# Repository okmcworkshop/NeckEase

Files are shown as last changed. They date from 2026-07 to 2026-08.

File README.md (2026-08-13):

# NeckEase 頸智鬆 - 實體裝置 neGuard



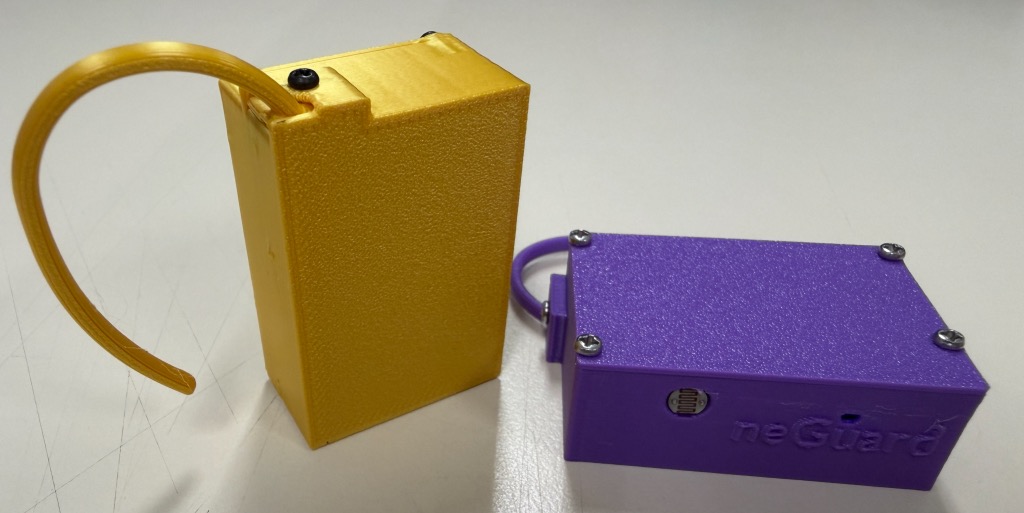
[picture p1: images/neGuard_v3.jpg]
neGuard圖片


📖 簡介
neGuard 是一個基於 ESP32-C3 的智慧姿勢矯正裝置。它能透過 BLE 與「NeckEase 頸智鬆」手機應用程式配對設定，之後便能離線獨立運作，即時監測你的頭部角度。當偵測到不良姿勢（如「烏龜頸」）過久時，neGuard 會以震動提醒，幫助你養成良好的姿勢習慣。

本專案專為 DIY 愛好者 及 STEAM 教育 設計，所有零件、程式碼和 3D 列印檔案皆已開源。我們希望藉此啟發對科技有興趣的同學，能一步一腳印地參考實踐，進而發揮創意，發明更多有益他人的作品。

✨ 功能特色
姿勢即時監測：內建 MPU-6050 陀螺儀，精準偵測頭部前傾角度。

離線獨立運作：與手機配對設定後，即可獨立使用，無需持續連接手機。

震動即時提醒：當姿勢不良時間超過設定值，內建震動馬達會溫和提醒。

低功耗藍牙 (BLE)：使用 ESP32-C3 的 BLE 功能，與手機應用程式進行配對與設定。

DIY 友善設計：採用常見、易於取得的電子零件，搭配 3D 列印外殼，組裝簡單。

** 與應用程式配對及設定之後，neGuard 保留參數儲存到 EEPROM，neGuard 開機30秒後會停止藍牙功能節省電力。如改動「角度閾值」和「持續時間」，在neGuard開機30秒內打開手機應用程式重新設定。 **

🧩 硬體需求
以下是製作 neGuard 所需的完整零件清單：
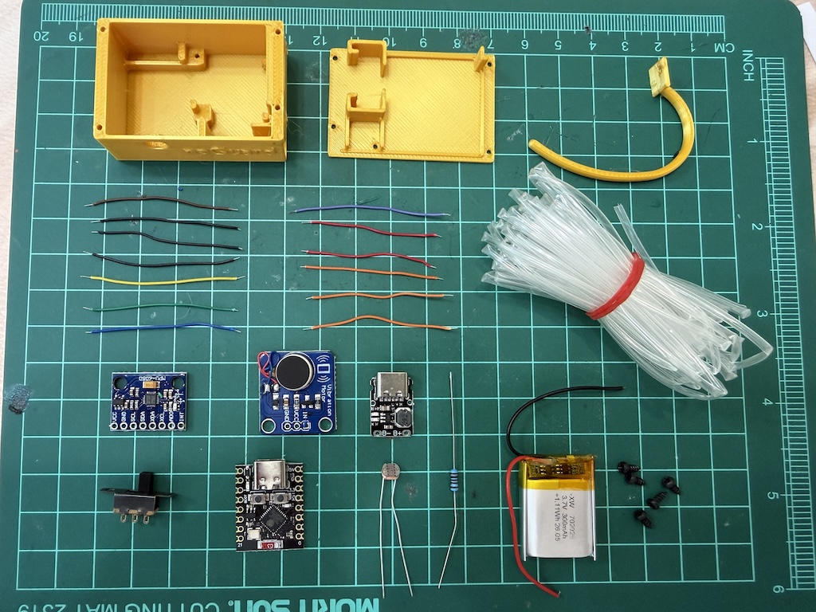
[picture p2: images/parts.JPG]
零件清單

### 硬體需求清單

- **微控制器**：ESP32-C3 Supermini 開發板 × 1（核心運算單元，支援 BLE）
- **陀螺儀**：MPU-6050 (I2C) × 1（偵測頭部角度）
- **光敏電阻**：5549 × 1（用於判斷環境光照度）
- **電阻**：10kΩ × 1（配合光敏電阻使用）
- **震動馬達模組**：1020 扁平震動馬達 × 1（提供震動提醒）
- **鋰電池充電模組**：5V 充電模組 (Type-C) × 1（為鋰電池充電）
- **電源開關**：SS-12F15 3腳2檔 滑動開關 × 1（控制裝置電源）
- **鋰電池**：702025 3.7V 300mAh LiPo × 1（裝置電源）
- **連接線**：AWG26 杜邦線/軟矽膠線（用於電路連接）
- **熱縮通**：少量(絕緣，避免短路)
- **螺絲**：M2x5不鏽鋼自攻螺絲 x 6
- **雙面膠**：少量(用於固定MPU6050 及 ESP32-C3)

🔧 組裝與設定指南
1. 電路連接 (接線圖)
請參考以下接線圖進行焊接。確保所有連接牢固，震動馬達及光敏電阻需加上熱縮通絕緣，避免短路。

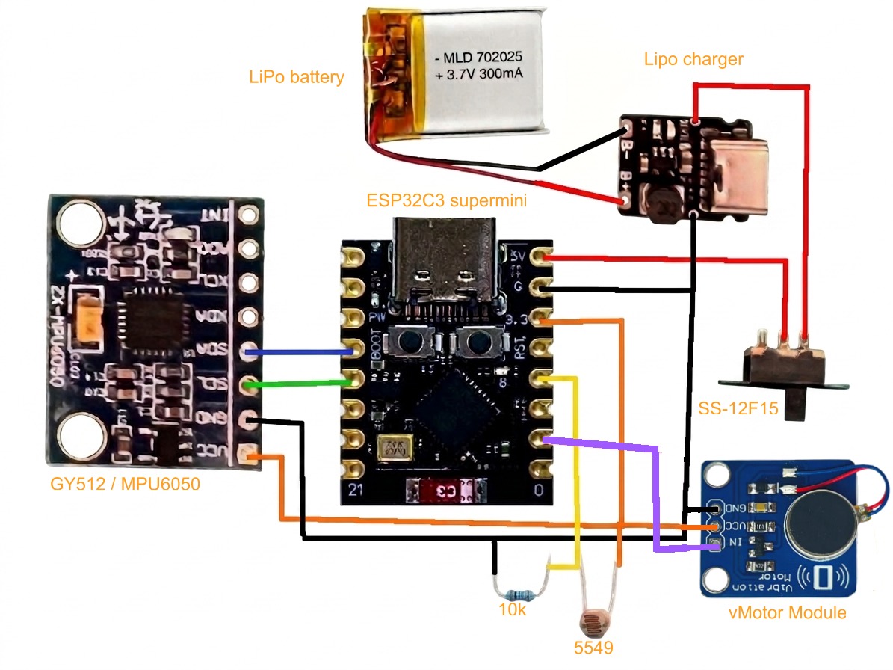
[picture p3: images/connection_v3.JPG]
接線圖


| 步驟 | 連接點 A | 連接點 B | 說明 |
| :---: | :--- | :--- | :--- |
| 1 | 外部 5V 電源 | ESP32-C3 5V 輸入端 | 為開發板提供電源 |
| 2 | ESP32-C3 3.3V | MPU-6050 VCC、光敏電阻一端、震動馬達正極 | 提供電源給 MPU-6050、光敏電阻分壓電路及震動馬達 |
| 3 | ESP32-C3 GND | 所有零件 GND（馬達、感測器、電晶體等） | 全部共地，形成完整迴路 |
| 4 | ESP32-C3 GPIO 1 | 震動馬達模組 IN | 輸出震動馬達控制訊號 |
| 5 | 光敏電阻 另一端 | GPIO 3 及 10kΩ 電阻 一端 | 分壓電路中間節點（ADC 讀取點） |
| 6 | 10kΩ 電阻 另一端 | ESP32-C3 GND | 分壓電路下端接地 |
| 7 | MPU-6050 SDA 腳位 | ESP32-C3 GPIO 8 | I2C 資料線 |
| 8 | MPU-6050 SCL 腳位 | ESP32-C3 GPIO 9 | I2C 時脈線 |
| 9 | MPU-6050 GND 腳位 | ESP32-C3 GND | 感測器接地 |

電路小提示：

# ESP32-C3 震動馬達模組 + 光敏電阻 驅動電路 (GPIO 1 控制馬達)

## 震動馬達模組驅動接線（GPIO 1）

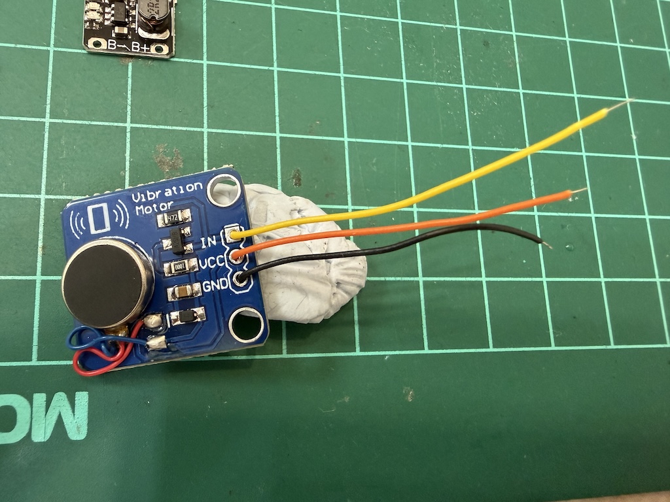
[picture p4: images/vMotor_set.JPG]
震動馬達 驅動電路


## 電路運作原理

- **GPIO 1 輸出高電平（3.3V）** → 模組內三極管基極獲得足夠電流 → 電晶體飽和導通 → 馬達獲得電流而振動。
- **GPIO 1 輸出低電平（0V）** → 電晶體截止 → 馬達停止。
- **續流二極體**：在馬達關斷瞬間，線圈產生反向感應電動勢（可達數十伏），二極體提供通路將其釋放，保護 三極管 不被擊穿。
- **光敏電阻**：光線越暗，阻值越大，分壓點電壓越高（ADC 數值越大）；光線越亮，阻值越小，電壓越低。

- NPN 電晶體開關原理是：電流從 C 流向 E（C → E），所以 負載（馬達）要接在 C 腳，E 腳要直接接地，這樣開關才能完全導通。

- 二極體 是反向並聯在馬達兩端（陰極接正極、陽極接負極），用來吸收馬達關斷時產生的「反向感應電動勢」，保護 三極管 不被高壓擊穿。

## 光敏電阻（光線感測）接線（GPIO 3）

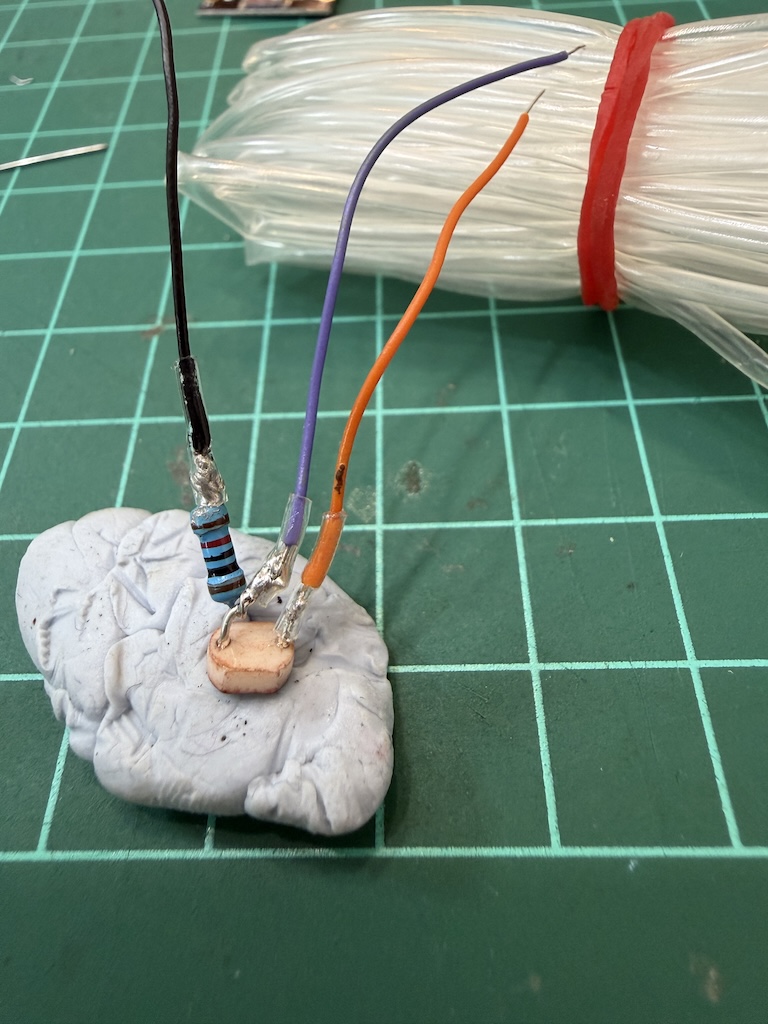
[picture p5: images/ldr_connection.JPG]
光敏電阻


| 步驟 | 連接點 A | 連接點 B | 說明 |
| :---: | :--- | :--- | :--- |
| 1 | 光敏電阻 **一端** | ESP32-C3 **3.3V** | 分壓電路上端 |
| 2 | 光敏電阻 **另一端** | **10kΩ 電阻** 之一端 及 **GPIO 3** | 分壓節點（ADC 讀取點） |
| 3 | **10kΩ 電阻** 之另一端 | ESP32-C3 **GND** | 分壓電路下端 |

** 在焊接處加上熱縮通絕緣 **

## 為什麼需要「分壓電路」？

- ESP32-C3 的 ADC（類比數位轉換器）**只能讀取電壓（0~3.3V）**，無法直接讀取電阻值。
- 光敏電阻是一個**可變電阻**，單獨接到 GPIO 時，因 GPIO 輸入阻抗極高，幾乎無電流流過，電壓恆為 3.3V，無法感測變化。
- 因此必須串聯一顆固定電阻（10kΩ），形成電流迴路，根據歐姆定律，分壓點電壓會隨光敏電阻阻值變化而改變，ADC 才能讀出有意義的數值。
- 選用 **10kΩ** 是常見工程值，因典型光敏電阻在室內光下約 10k~20kΩ，此組合能使輸出電壓變化範圍最大且線性度佳。

## MPU6050（陀螺儀）I2C接線（GPIO 8 SDA, GPIO 9 SCL）

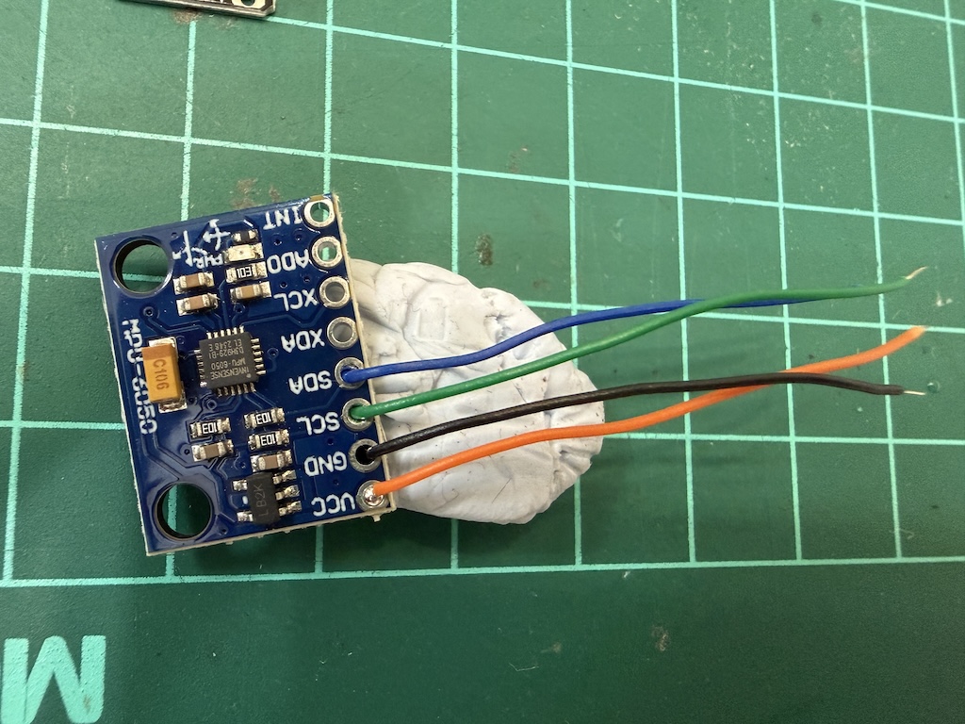
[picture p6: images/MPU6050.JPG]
MPU6050


## ESP32C3 以及 電源：

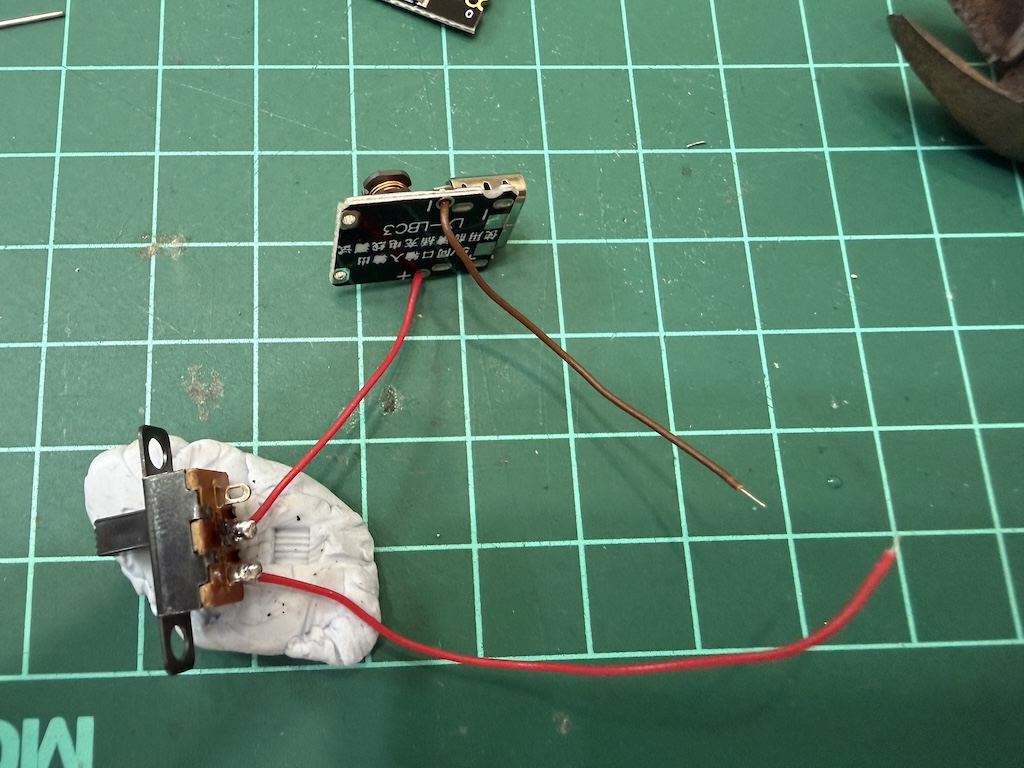
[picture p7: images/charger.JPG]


- 引出充電模組的 OUT- 和 OUT+ 經過「電源開關」。

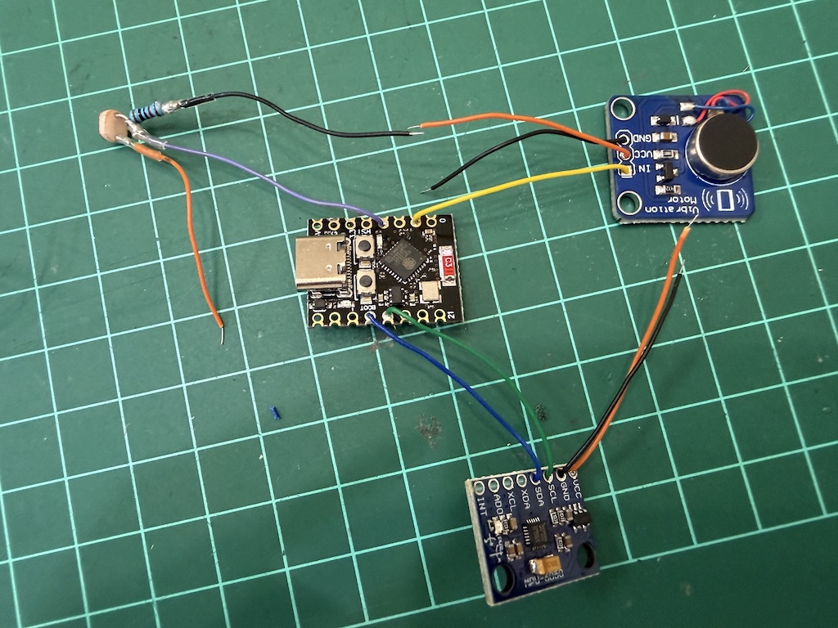
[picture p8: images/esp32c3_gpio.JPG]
ESP32C3


- MPU6050 SDA > 8，SCL > 9 。 震動馬達模組 IN > 1 。 光敏電阻 > 3 。

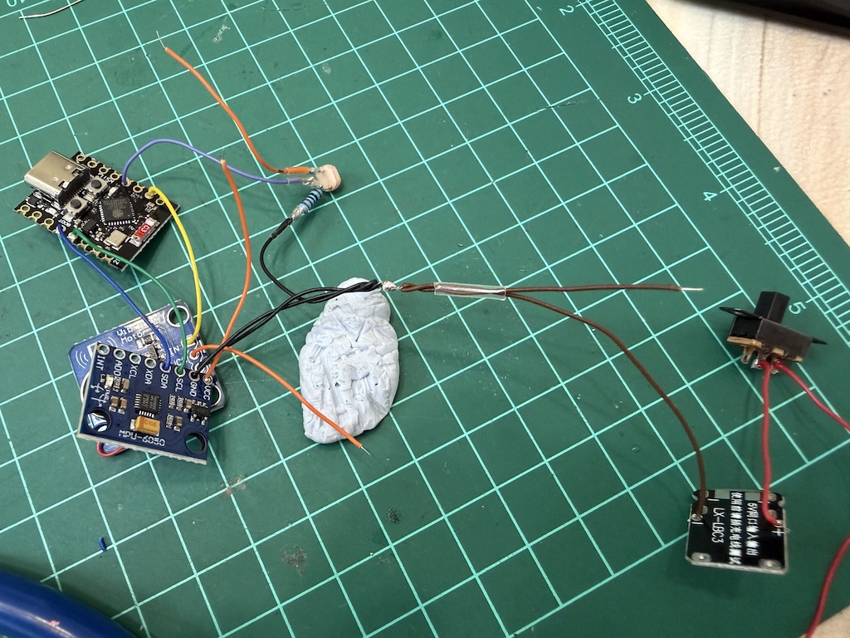
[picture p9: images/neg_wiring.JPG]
共地接線


- 充電模組的 OUT- 連接 MPU6050、震動馬達模組、光敏電阻 負極 並且引出 預留接駁ESP32C3 負極。

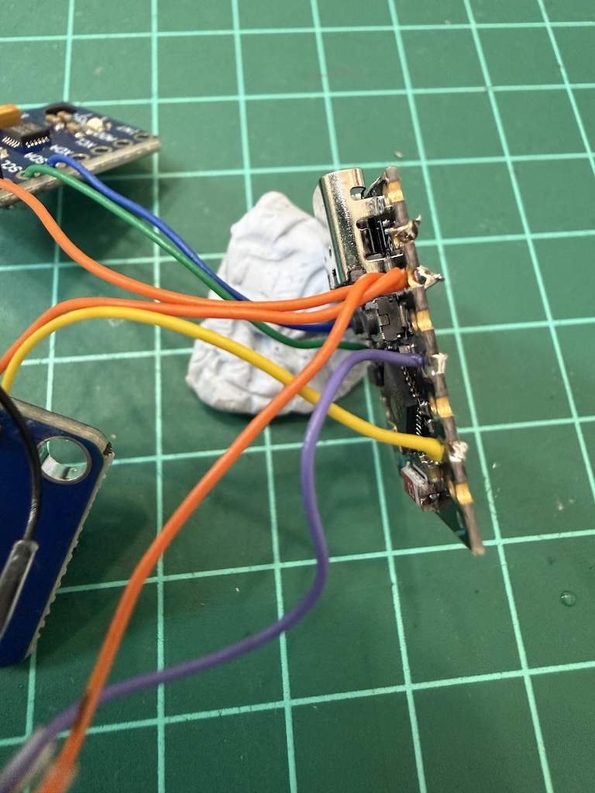
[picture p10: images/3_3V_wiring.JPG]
3.3V接線


- MPU6050、震動馬達模組、光敏電阻 正極連接 ESP32C3 3.3V

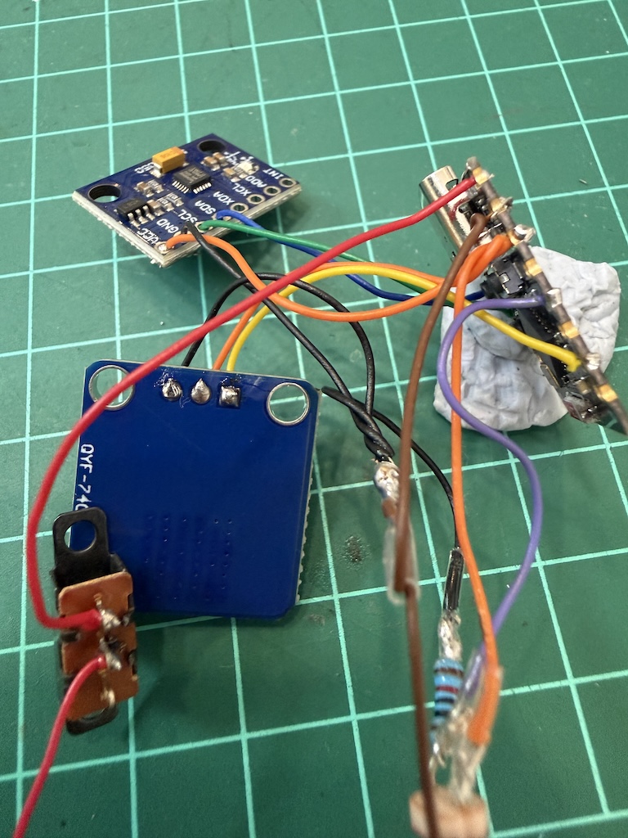
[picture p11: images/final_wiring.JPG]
5V接線


- OUT+經過「電源開關」接到 ESP32-C3 的 5V ，共地負極接駁ESP32C3 負極。

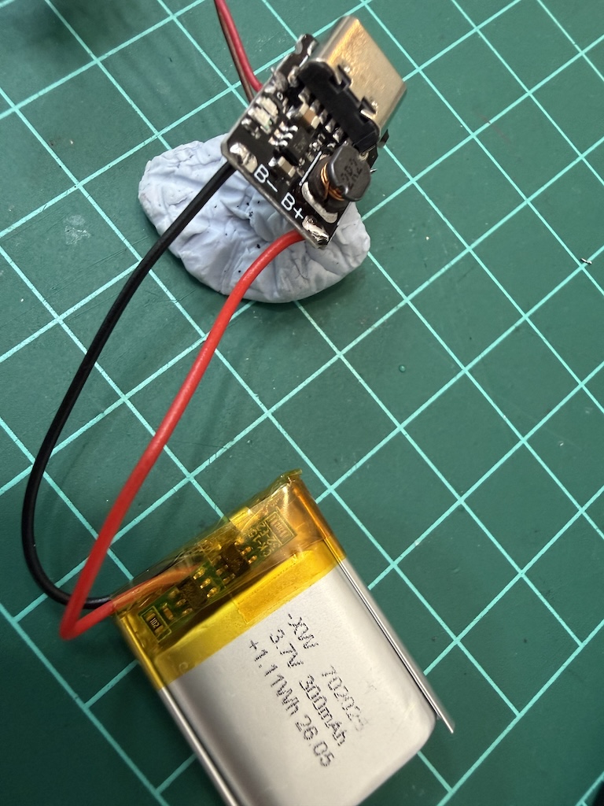
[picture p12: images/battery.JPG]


- 最後鋰電池透過「充電模組」的 BAT+ 和 BAT- 連接。

# 2. 3D 列印外殼

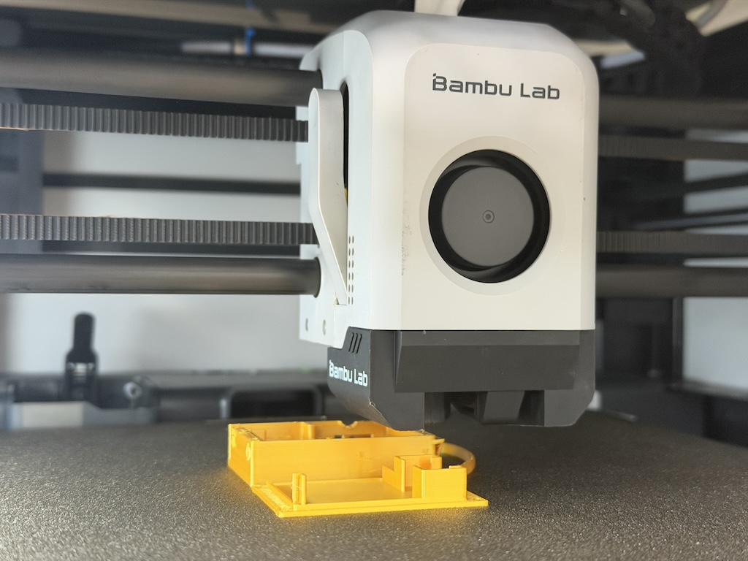
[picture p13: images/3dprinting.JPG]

請使用以下建議設定列印外殼。STL 檔案可以在 hardware/3d_print/ 資料夾中找到。

材料：PLA 或 PLA+ (約 10g)

噴嘴直徑：0.4mm

層高：0.28mm

外牆層數 (Wall Loops)：3

填充率：20%

支撐：不需要支撐。

備有大小掛耳，適配不同人士使用。

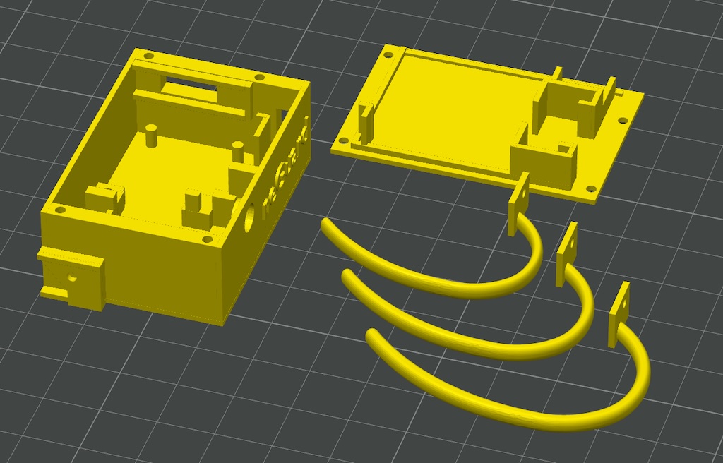
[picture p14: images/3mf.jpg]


# 3. 軟體燒錄 (韌體)
韌體使用 C++ 編寫，在 Arduino IDE 中開發。

安裝 Arduino IDE：從 官方網站 下載並安裝。

安裝 ESP32 開發板套件：

開啟 Arduino IDE，進入 檔案 > 偏好設定。

在「額外的開發板管理器網址」中，加入：https://espressif.github.io/arduino-esp32/package_esp32_index.json

進入 工具 > 開發板 > 開發板管理員，搜尋 esp32 並安裝 esp32 套件。

安裝所需的程式庫：

在 草稿碼 > 匯入程式庫 > 管理程式庫 中，搜尋並安裝：

MPU6050 by Electronic Cats (或 Adafruit MPU6050)

ESP32 BLE Arduino (通常已內建)

開啟韌體專案：

下載本倉庫的程式碼，在 Arduino IDE 中開啟 firmware/neGuard_v2.ino 檔案。

選擇開發板與連接埠：

在 工具 > 開發板 中，選擇 ESP32C3 Dev Module。

在 工具 > 連接埠 中，選擇你的 ESP32-C3 對應的 COM 連接埠。

上傳程式碼：

點擊 「上傳」 按鈕。等待編譯並上傳完成。

# 4. 組裝說明

第1步) 先檢查電線有否破損、斷裂或其他可能導致短路的情況

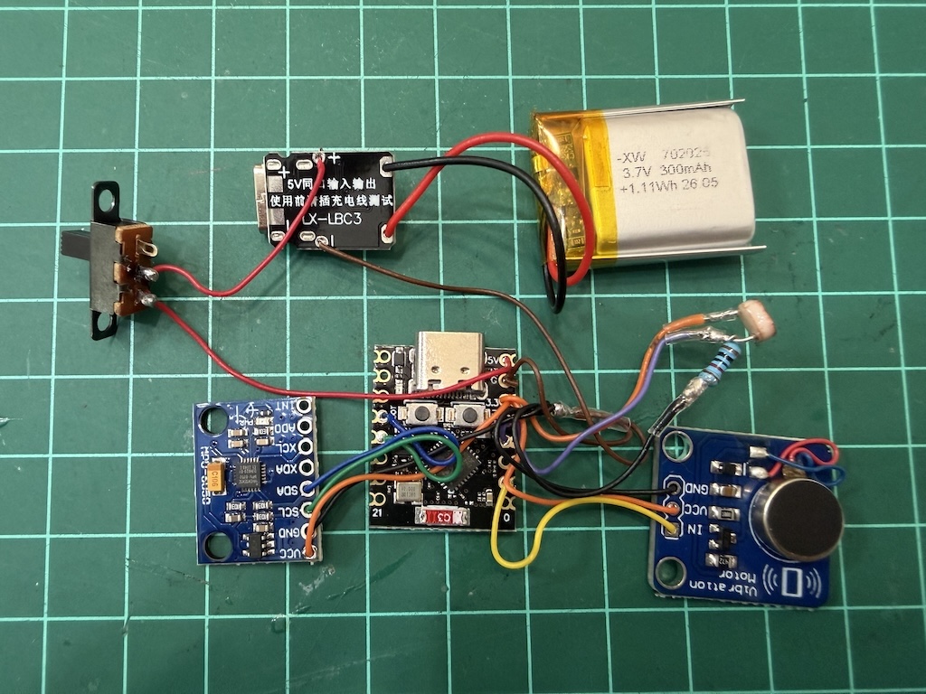
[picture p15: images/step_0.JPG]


將 neGuard 開關掣撥到接通，進行測試 > 開啟"NeckEase 頸智鬆" 應用程式 > "姿態提示" 頁面 > 點擊螢幕有上方藍牙 icon
如果顯示 "已找到 neGuard" > 關閉 neGuard 電源繼續組裝程序

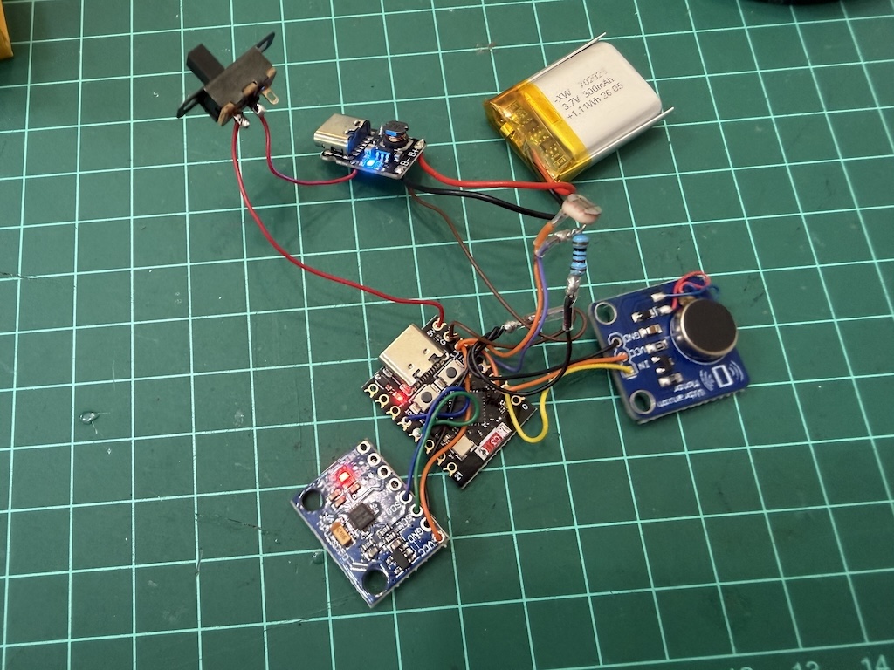
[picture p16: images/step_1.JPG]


第2步) 將充電模組放入3D打印外殼

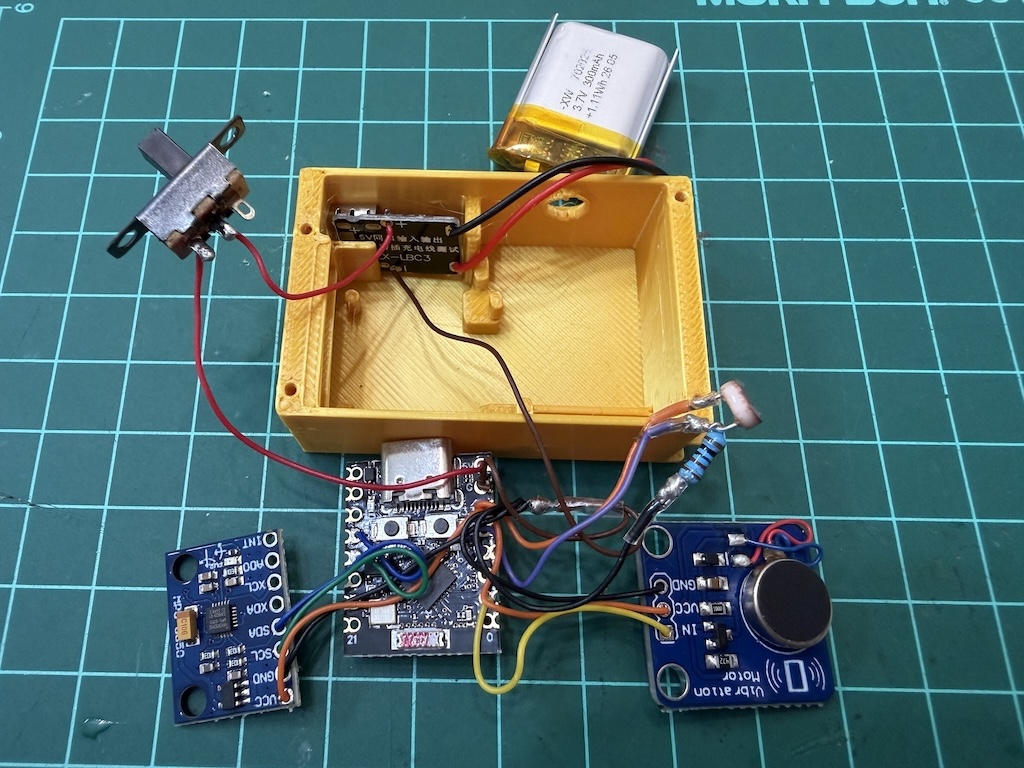
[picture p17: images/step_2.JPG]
組裝說明 - 2


第3步) MPU6050 及 ESP32C3 背面加上雙面膠

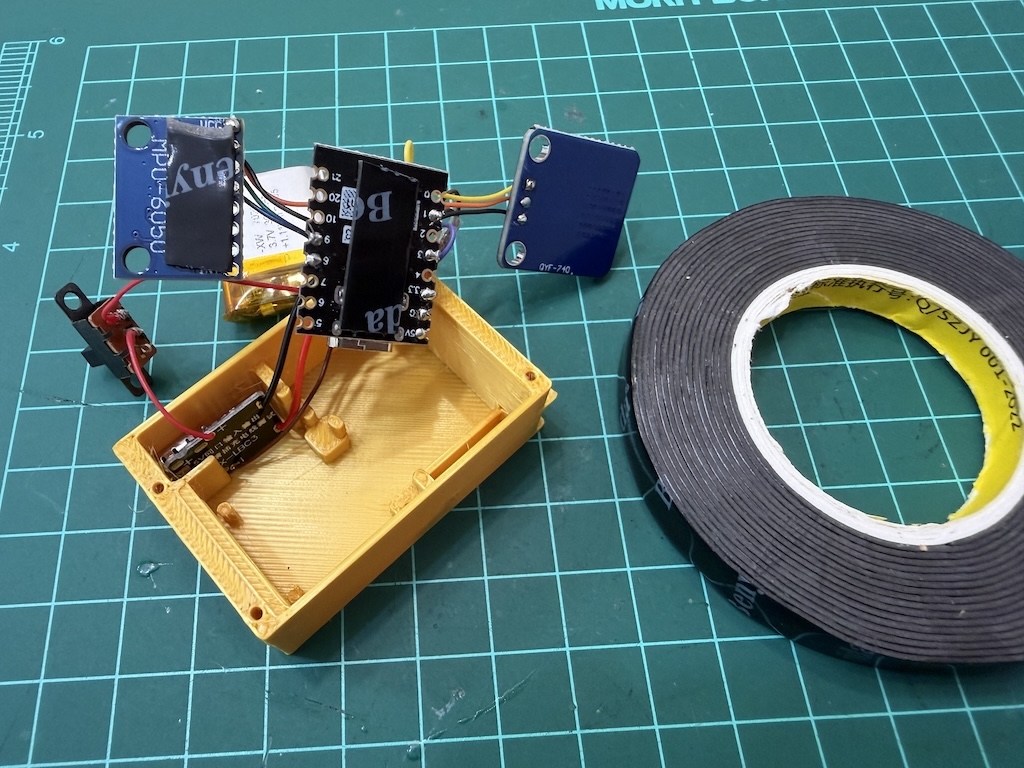
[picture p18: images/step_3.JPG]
組裝說明 - 3


第4步) 放入 MPU6050 及 ESP32-C3，稍加壓力固定 

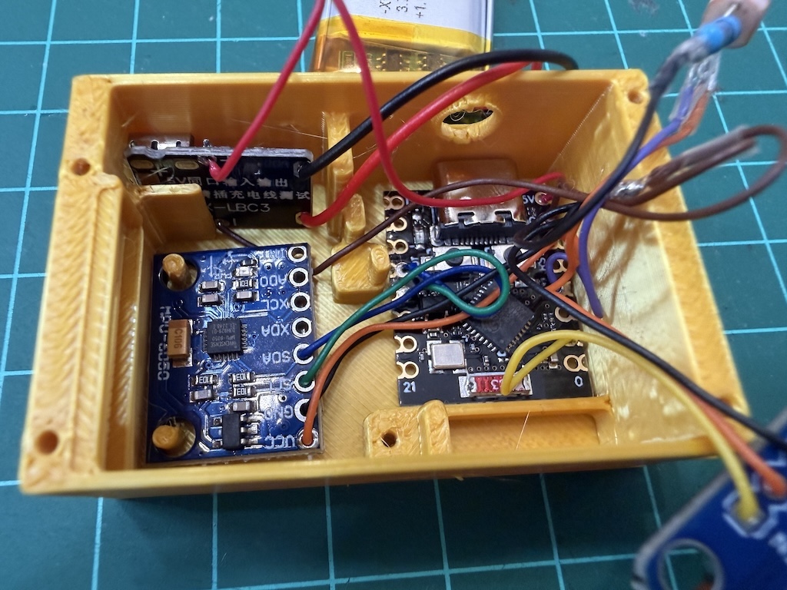
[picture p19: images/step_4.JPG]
組裝說明 - 4


第5步) 放入 5549 光敏電阻

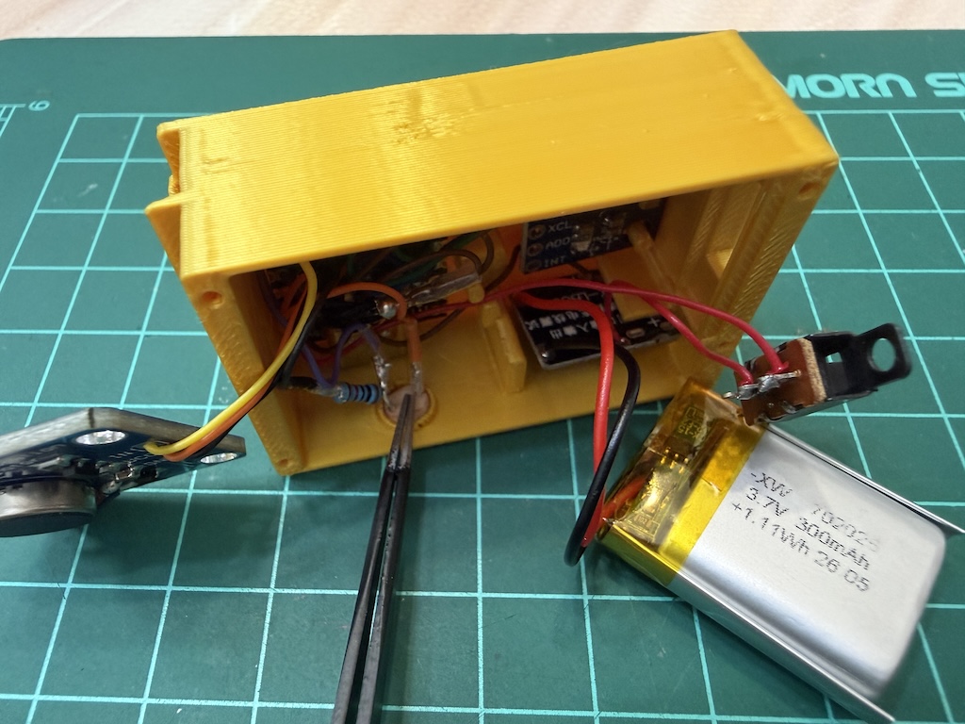
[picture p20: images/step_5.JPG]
組裝說明 - 5


第6步) 將震動馬達及模組主板分離(不處理有機會放不進外殼)

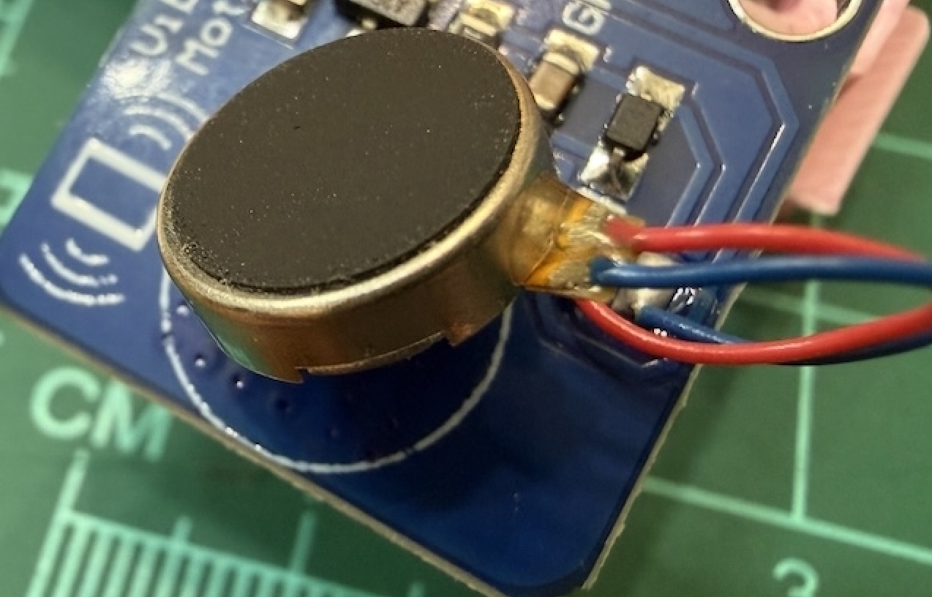
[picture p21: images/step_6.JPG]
組裝說明 - 6


第7步) 如圖片顯示把震動馬達放好並固定(留意電線位置)

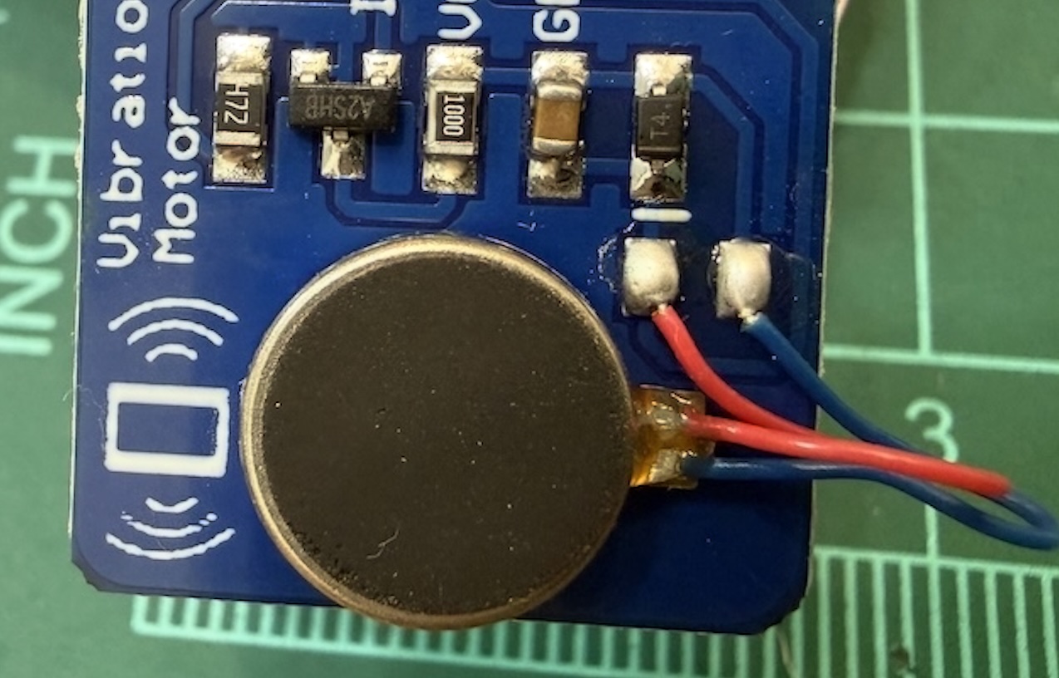
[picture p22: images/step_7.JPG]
組裝說明 - 7


第8步) 放入 震動馬達模組，並用螺絲固定好

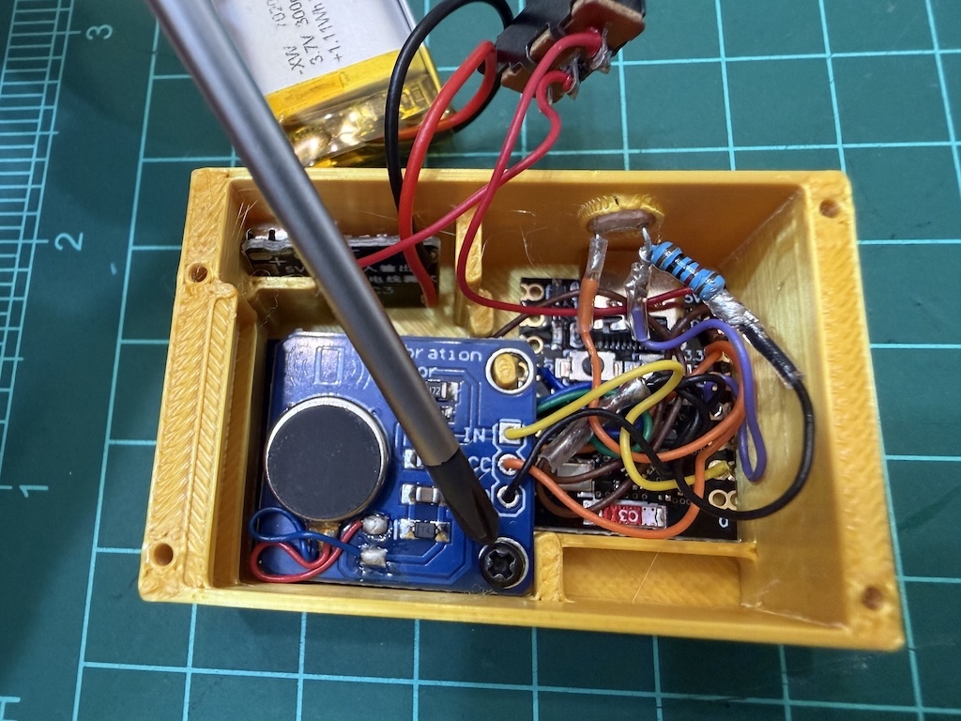
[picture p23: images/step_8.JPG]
組裝說明 - 8


第9步) 電池放在外殼頂蓋

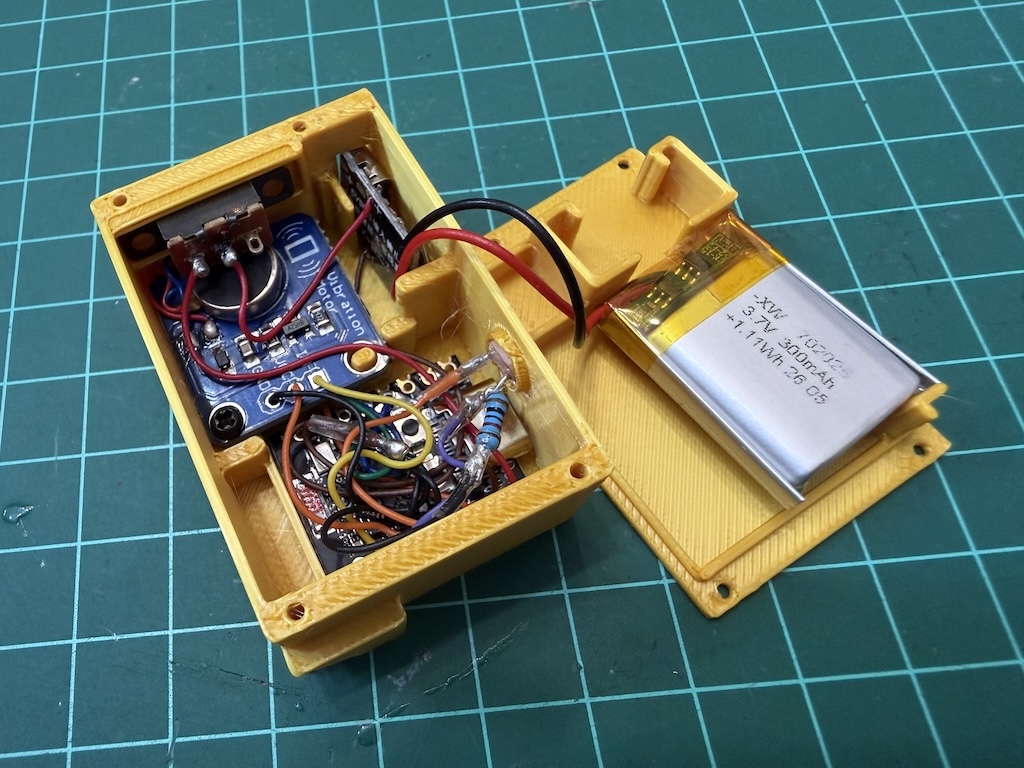
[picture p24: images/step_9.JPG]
組裝說明 - 9


第10步) 蓋好頂蓋，並用螺絲固定好

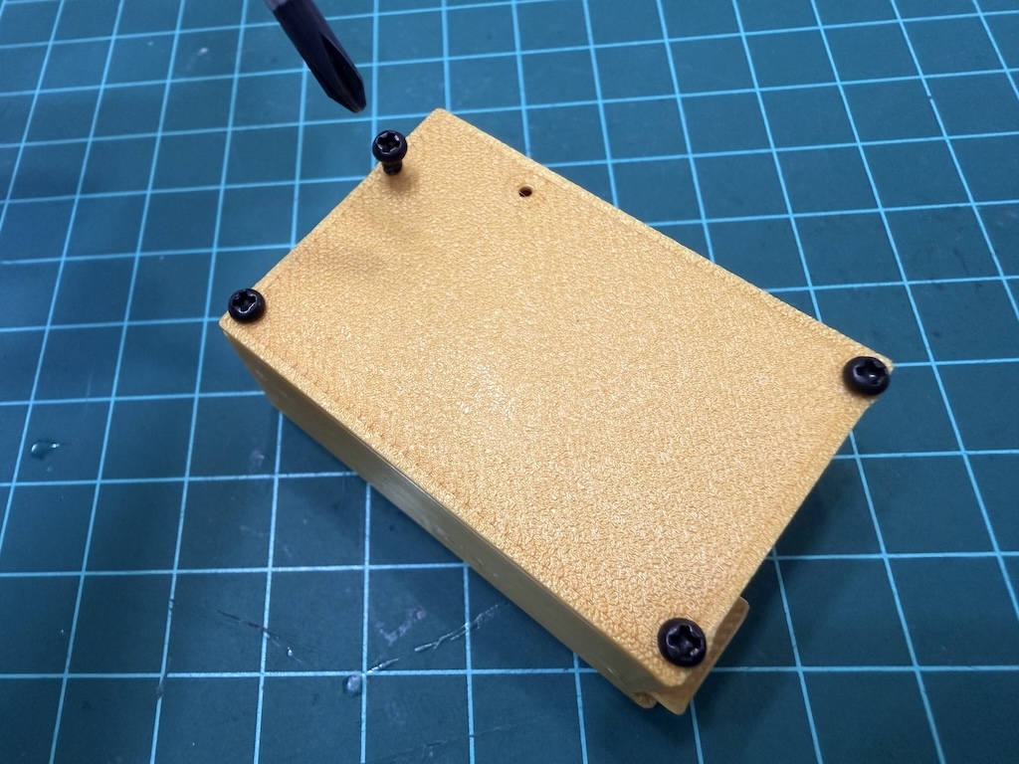
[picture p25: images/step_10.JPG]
組裝說明 - 10


第11步) 加上掛耳

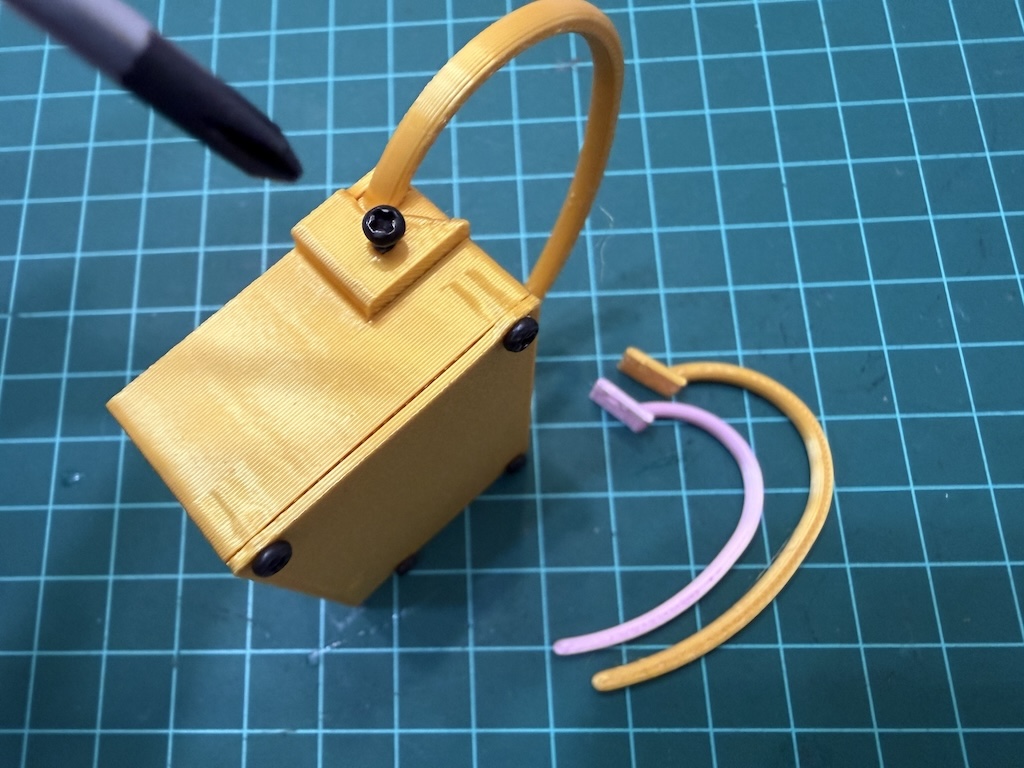
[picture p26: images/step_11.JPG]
組裝說明 - 11


# 恭喜你完成了

# 📱 使用說明
下載手機應用程式：在 Google Play 或 App Store 商店搜尋並下載 「NeckEase 頸智鬆」。

開啟裝置電源：將 neGuard 的電源開關撥至「ON」位置。

配對與設定：

打開手機應用程式，點擊「姿態提示」功能。

按下螢幕右上方"藍牙"標誌，會自動掃描附近的 neGuard 裝置，點擊進行配對。

依照手機畫面上的引導，設定提醒的「角度閾值」和「持續時間」。

開始使用：設定完成後，將 neGuard 夾在(左)耳朵上。當你的頭部前傾角度超過設定值且持續時間過長時，neGuard 便會震動提醒你。此後，即使手機不在身邊，neGuard 也能獨立工作。

** 與應用程式配對及設定之後，neGuard 保留參數儲存到 EEPROM，neGuard 開機30秒後會停止藍牙功能節省電力。如改動「角度閾值」和「持續時間」，在neGuard開機30秒內打開手機應用程式重新設定。 **

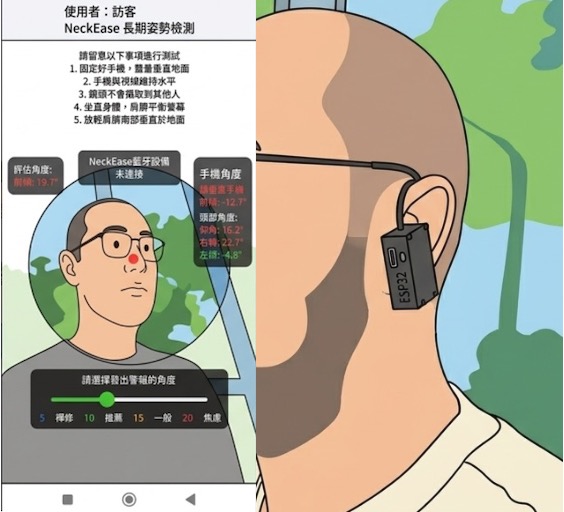
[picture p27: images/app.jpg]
產品圖片


# 📜 授權資訊
本專案 (包含韌體、硬體設計檔案、3D 列印檔案) 採用 MIT License 開源授權。

這意味著你可以：

✅ 自由使用、複製、修改、合併、出版發行、散布、再授權及販售軟體及硬體檔案的副本。

✅ 將本專案用於任何用途，包括商業用途。

唯一的條件是：你必須在所有的副本或重要部分中，包含版權聲明及本許可聲明。

詳細授權條款請參閱本倉庫的 LICENSE 檔案。

# 🤝 如何貢獻
我們非常歡迎任何形式的貢獻！如果你有好的想法、發現了 Bug，或是想改善文件，歡迎：

Fork 本專案。

建立你的功能分支 (git checkout -b feature/AmazingFeature)。

提交你的修改 (git commit -m 'Add some AmazingFeature')。

推送至分支 (git push origin feature/AmazingFeature)。

開啟一個 Pull Request。

祝你組裝愉快，輕鬆告別烏龜頸！

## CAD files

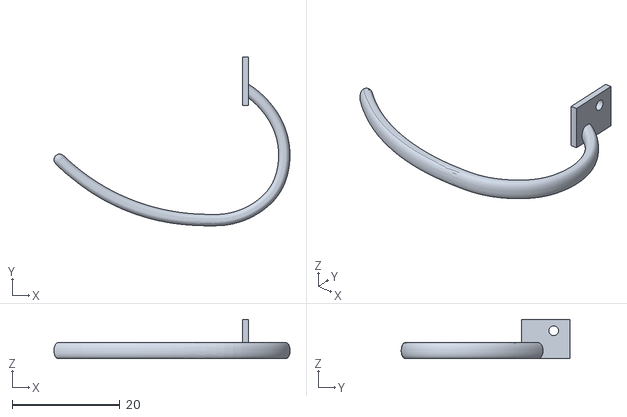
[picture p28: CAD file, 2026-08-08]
hardware/3d_print/V3_ear_clip_M.stl
43.8 x 31.3 x 7.32

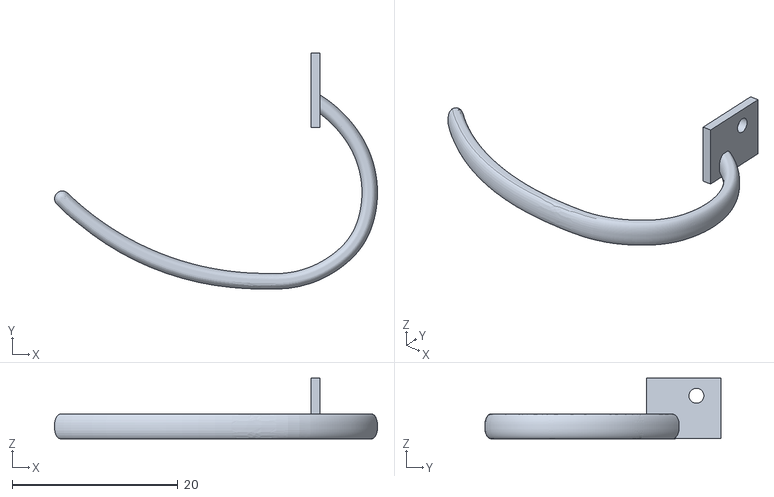
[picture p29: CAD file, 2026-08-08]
hardware/3d_print/V3_ear_clip_S.stl
39.0 x 28.5 x 7.32

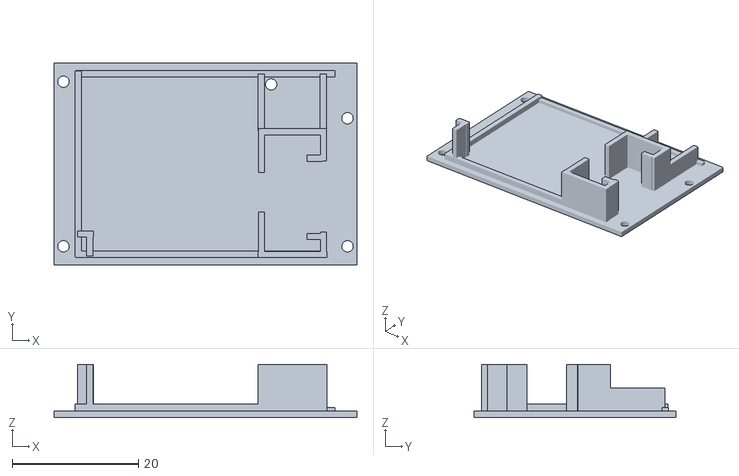
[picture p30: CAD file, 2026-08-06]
hardware/3d_print/neGuard_V3_cover.stl
48.0 x 32.0 x 8.40

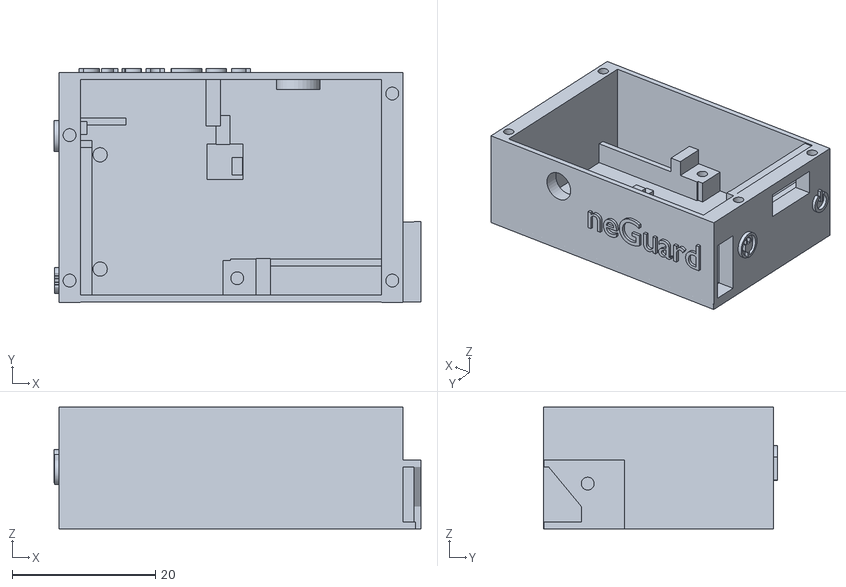
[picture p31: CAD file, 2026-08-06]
hardware/3d_print/neGuard_V3.stl
51.2 x 32.6 x 17.0

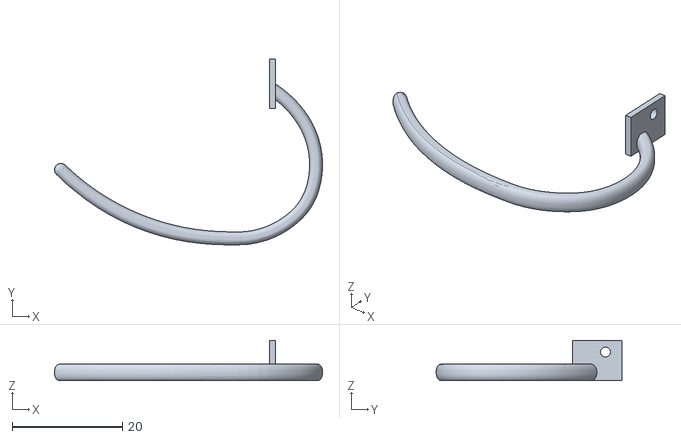
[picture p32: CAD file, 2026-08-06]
hardware/3d_print/V3_ear_clip_L.stl
48.7 x 33.7 x 7.32

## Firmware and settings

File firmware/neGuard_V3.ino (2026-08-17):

#include <Wire.h>
#include <BLEDevice.h>
#include <BLEUtils.h>
#include <BLEServer.h>
#include <Preferences.h>
#include <MPU6050_tockn.h>
#include <esp_sleep.h>  // 引入睡眠管理標頭檔
#include <WiFi.h>       // 用於確保 Wi-Fi 模組徹底關閉
#include "esp_bt.h"

MPU6050 mpu6050(Wire);

// ---------- 感測器資料結構 ----------
struct SensorData {
  float roll;
  float pitch;
  int ldr;
  float volt;
};

// ---------- BLE UUID ----------
#define SERVICE_UUID "6E400001-B5A3-F393-E0A9-E50E24DCCA9E"
#define IMU_CHAR_UUID "6E400002-B5A3-F393-E0A9-E50E24DCCA9F"
#define SWITCH_CHAR_UUID "6E400003-B5A3-F393-E0A9-E50E24DCCA9E"

// ---------- 全域 BLE 物件 ----------
BLEServer* pServer = NULL;
BLECharacteristic* pImuCharacteristic = NULL;
BLECharacteristic* pSwitchCharacteristic = NULL;

// ---------- 姿勢與濾波變數 ----------
float angleRoll = 0, anglePitch = 0;
float dt = 0;
unsigned long lastTime = 0;
unsigned long lastHighFreqUpdate = 0;
float alpha = 0.05;

// 腳位設定
const int LIGHT_SENSOR_PIN = 3;  // GPIO3
const int V_MOTOR_PIN = 1;       // GPIO1

// 警報與狀態標誌
unsigned long alarmStartTime = 0;
unsigned long lastBlinkTime = 0;
int _BlinkCap = 1000;
bool alarmActive = false;
bool deviceConnected = false;
int postureStartTime = 0;

// 校準與姿態判斷變數
float calRoll_10 = 0, calRoll_15 = 0, calRoll_20 = 0, calRoll_25 = 0;  // 對應前傾的 Gyro Roll
float thresholdRoll = 0;                                               // 使用者選擇的閾值所對應的 Gyro Roll
int durationSeconds = 5;                                               // 持續時間（秒）
bool calibrated = false;                                               // 是否已收到校準資料

//unsigned long postureStartTime = 0;  // 姿勢不良開始計時的時間點
bool alertTriggered = false;         // 是否已觸發振動提醒（持續振動中）

// BLE 計時與儲存
Preferences preferences;         // Preferences 物件
bool bleActive = false;          // 是否處於廣播有效期間（用於計時控制）
bool bleInitialized = false;     // 是否已初始化 BLE（避免重複 deinit）
unsigned long bleStartTime = 0;  // 開始計時的時間點

// ---------- 輔助函式：馬達震動  ----------
void blinkMotor(int times) {
  for (int i = 0; i < times; i++) {
    digitalWrite(V_MOTOR_PIN, HIGH);
    delay(200);
    digitalWrite(V_MOTOR_PIN, LOW);
    delay(100);
  }
}

// ---------- 用於連線debug  ----------
void _print_gyro_data() {
  Serial.print("Roll: ");
  Serial.print(angleRoll, 2);
  Serial.print("\tPitch: ");
  Serial.println(anglePitch, 2);
}

void shutdownBLECompletely() {
  Serial.println("開始關閉 BLE 與藍牙控制器...");

  if (pServer) {
    pServer->getAdvertising()->stop();
  }

  // 1. 釋放 BLEDevice 物件與內部 Task
  BLEDevice::deinit(true);

  // 2. 徹底關閉並釋放底層 BT Controller 資源
  if (esp_bt_controller_get_status() == ESP_BT_CONTROLLER_STATUS_ENABLED) {
    esp_bt_controller_disable();
  }
  if (esp_bt_controller_get_status() == ESP_BT_CONTROLLER_STATUS_INITED) {
    esp_bt_controller_deinit();
  }

  // 3. 釋放 BLE 記憶體空間給系統使用
  esp_bt_mem_release(ESP_BT_MODE_BLE);

  bleInitialized = false;
  bleActive = false;
  Serial.println("BLE 已完全釋放，準備安全進入 Light Sleep");
}

// ---------- BLE 回呼類別 ----------
class MyServerCallbacks : public BLEServerCallbacks {
  void onConnect(BLEServer* pServer) override {
    deviceConnected = true;
    Serial.println("Client connected");
  }
  void onDisconnect(BLEServer* pServer) override {
    deviceConnected = false;
    Serial.println("Client disconnected");
    if (bleInitialized) {
      pServer->startAdvertising();
    }
  }
};

class SwitchCharacteristicCallbacks : public BLECharacteristicCallbacks {
  void onWrite(BLECharacteristic* pCharacteristic) override {
    String value = pCharacteristic->getValue();
    value.trim();

    // --- 處理App警報 ---
    if (value == "alarm") {
      alarmActive = true;
      alarmStartTime = millis();
    }

    // --- 處理校準資料（格式：cal,77.8,70.8,66.5,60.5,66.5,10） ---
    if (value.startsWith("cal,")) {
      String data = value.substring(4);
      int comma1 = data.indexOf(',');
      int comma2 = data.indexOf(',', comma1 + 1);
      int comma3 = data.indexOf(',', comma2 + 1);
      int comma4 = data.indexOf(',', comma3 + 1);
      int comma5 = data.indexOf(',', comma4 + 1);

      if (comma1 != -1 && comma2 != -1 && comma3 != -1 && comma4 != -1 && comma5 != -1) {
        calRoll_10 = data.substring(0, comma1).toFloat();
        calRoll_15 = data.substring(comma1 + 1, comma2).toFloat();
        calRoll_20 = data.substring(comma2 + 1, comma3).toFloat();
        calRoll_25 = data.substring(comma3 + 1, comma4).toFloat();
        thresholdRoll = data.substring(comma4 + 1, comma5).toFloat();
        durationSeconds = data.substring(comma5 + 1).toInt();

        calibrated = true;

        // ----- 儲存參數到 Preferences (用於離線運作)-----
        preferences.begin("neGuard", false);
        preferences.putFloat("threshold", thresholdRoll);
        preferences.putInt("duration", durationSeconds);
        preferences.end();

        postureStartTime = 0;
         alertTriggered = false;

        // ----- 重置 BLE 計時器（若 BLE 仍在運行） -----
        if (bleInitialized) {
          bleStartTime = millis();
          bleActive = true;
        }
      }
    }
  }
};

void setupBLE() {
  BLEDevice::init("neGuard");
  pServer = BLEDevice::createServer();
  pServer->setCallbacks(new MyServerCallbacks());

  BLEService* pService = pServer->createService(SERVICE_UUID);

  pImuCharacteristic = pService->createCharacteristic(
    IMU_CHAR_UUID,
    BLECharacteristic::PROPERTY_READ | BLECharacteristic::PROPERTY_NOTIFY);

  pSwitchCharacteristic = pService->createCharacteristic(
    SWITCH_CHAR_UUID,
    BLECharacteristic::PROPERTY_READ | BLECharacteristic::PROPERTY_WRITE);
  pSwitchCharacteristic->setCallbacks(new SwitchCharacteristicCallbacks());

  pService->start();

  BLEAdvertising* pAdvertising = pServer->getAdvertising();
  pAdvertising->addServiceUUID(SERVICE_UUID);
  pAdvertising->setScanResponse(true);
  pAdvertising->setMinPreferred(0x12);
  pServer->startAdvertising();

  bleInitialized = true;
}

void setup() {
  Serial.begin(115200);

  // 關閉 Wi-Fi 模組節省電力
  WiFi.mode(WIFI_OFF);

  // 初始化 I2C （SDA=8, SCL=9）
  Wire.begin(8, 9);
  Wire.setClock(100000);

  // 初始化 MPU6050
  mpu6050.begin();

  // 配置光敏電阻腳位（ADC）
  analogReadResolution(12);
  pinMode(LIGHT_SENSOR_PIN, INPUT);
  pinMode(V_MOTOR_PIN, OUTPUT);
  digitalWrite(V_MOTOR_PIN, LOW);

  // 讀取校準參數
  preferences.begin("neGuard", false);
  if (preferences.isKey("threshold") && preferences.isKey("duration")) {
    thresholdRoll = preferences.getFloat("threshold", 0);
    durationSeconds = preferences.getInt("duration", 5);
    calibrated = true;
    blinkMotor(3);
    //讀取成功震動3次
  } else {
    calibrated = false;
    blinkMotor(2);
    //沒有校準資料震動2次
  }
  preferences.end();

  // 5. 啟動 BLE
  setupBLE();

  if (calibrated) {
    bleStartTime = millis();
  }
  bleActive = true;

  lastTime = micros();
  Serial.println("設定完成");
}

void loop() {

  // 判斷當前採樣模式：BLE 仍在工作或手機已連線時，使用高頻模式 (20ms)
  bool isHighFrequencyMode = bleInitialized || deviceConnected;

  if (isHighFrequencyMode) {

    // ==========================================
    // 階段一：高頻模式 (50Hz / 20ms 週期) - 用於校準與 BLE 傳輸
    // ==========================================
    unsigned long nowMs = millis();
    if (nowMs - lastHighFreqUpdate >= 20) {
      lastHighFreqUpdate = nowMs;

      mpu6050.update();

      // 互補濾波姿態計算
      float accX = mpu6050.getAccX();
      float accY = mpu6050.getAccY();
      float accZ = mpu6050.getAccZ();
      float gyroX = mpu6050.getGyroX();
      float gyroY = mpu6050.getGyroY();

      float accelAnglePitch = atan2(-accX, sqrt(accY * accY + accZ * accZ)) * 180.0 / PI;
      float accelAngleRoll = atan2(accY, accZ) * 180.0 / PI;

      unsigned long nowUs = micros();
      dt = (nowUs - lastTime) / 1000000.0;
      lastTime = nowUs;
      if (dt > 0.1) dt = 0.1;

      angleRoll = alpha * accelAngleRoll + (1 - alpha) * (angleRoll + gyroX * dt);
      anglePitch = alpha * accelAnglePitch + (1 - alpha) * (anglePitch + gyroY * dt);

      uint16_t lightValue = analogRead(LIGHT_SENSOR_PIN);

      // BLE 通知 App
      if (deviceConnected && bleInitialized) {
        SensorData data;
        data.roll = angleRoll;
        data.pitch = anglePitch;
        data.ldr = lightValue;
        data.volt = 0.0;
        pImuCharacteristic->setValue((uint8_t*)&data, sizeof(data));
        pImuCharacteristic->notify();
        _print_gyro_data();
      }
    }

    // ----- 離線姿態判斷（校準後啟用） -----
    if (calibrated) {
      if (anglePitch < thresholdRoll) {
        if (!alertTriggered) {
          Serial.print("姿勢不良 > ");
          Serial.print((millis() - postureStartTime) / 1000);
          Serial.print(" >> ");
          _print_gyro_data();
          if (postureStartTime == 0) {
            postureStartTime = millis();
          } else {
            if (millis() - postureStartTime >= (unsigned long)durationSeconds * 1000) {
              alertTriggered = true;
              postureStartTime = millis();
              Serial.println("姿勢不良超過設定時間，啟動振動提醒！");
            }
          }
        }
      } else {
        if (alertTriggered) {
          digitalWrite(V_MOTOR_PIN, LOW);
          alertTriggered = false;
          Serial.println("姿勢已恢復，關閉振動");
          _print_gyro_data();
        }
        postureStartTime = 0;
      }
    }

    // ----- 處理手動警報（alarm）超時清除 -----
    if (alarmActive && (millis() - alarmStartTime >= 100)) {
      alarmActive = false;
      Serial.println("Alarm timer expired, flag cleared");
    }

    // ----- 馬達狀態統一控制 -----
    if (alertTriggered && millis() - lastBlinkTime >= _BlinkCap) {
      blinkMotor(1);
      lastBlinkTime = millis();
    } else if (alarmActive) {
      digitalWrite(V_MOTOR_PIN, HIGH);
    } else {
      digitalWrite(V_MOTOR_PIN, LOW);
    }

    // ---------- BLE 30 秒超時關閉判斷 ----------
    if (calibrated && bleActive && !deviceConnected) {
      if (millis() - bleStartTime >= 30000) {
        shutdownBLECompletely();
      }
    }
    delay(1);

  } else {
    Serial.println("isLowFrequencyMode");
    // ==========================================
    // 階段二：離線省電模式  - 30秒關閉 BLE 後切換至此
    // ==========================================
    mpu6050.update();
    float accX = mpu6050.getAccX();
    float accY = mpu6050.getAccY();
    float accZ = mpu6050.getAccZ();

    // 加速度計靜態姿態計算（無需陀螺儀高頻積分）
    anglePitch = atan2(-accX, sqrt(accY * accY + accZ * accZ)) * 180.0 / PI;
    angleRoll = atan2(accY, accZ) * 180.0 / PI;

    if (anglePitch < thresholdRoll) {
      Serial.println("姿勢不良！");
      blinkMotor(1);
    }

    Serial.println("Try Light Sleep");
    uint64_t sleepUs = (uint64_t)(durationSeconds * 1000) * 1000;

    // 設定睡眠定時器喚醒
    esp_sleep_enable_timer_wakeup(sleepUs);
    Serial.flush();  // 確保 Serial 列印完全輸出後才切斷 CPU 時鐘
    esp_light_sleep_start();
  }
}

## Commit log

2026-07-18 updated wiring.jpg
    updated wiring connection
2026-07-18 updated wiring.jpg
2026-07-18 updated neGuard_v1.ino (arduino IDE)
2026-07-18 updated neGuard_v2 stl file
    [neGuard_v2.stl, neGuard_v2_cover.stl]
2026-07-18 uploaded v2 case open jpg
2026-07-19 uploaded wiring_v2.jpg
2026-07-21 uploaded 2n2222 pinout & wiring jpg
2026-07-21 uploaded vibration motor connection photo
2026-08-06 Updated neGuard_V3 stl file
    [neGuard_V3.stl, neGuard_V3_cover.stl]
2026-08-08 uploaded V3_ear_clip_small.stl
    [V3_ear_clip_small.stl]
2026-08-08 Add S,M,L size ear clip stl file
    [V3_ear_clip_L.stl, V3_ear_clip_M.stl, V3_ear_clip_S.stl]
2026-08-10 Added assemble photo

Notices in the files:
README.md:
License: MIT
